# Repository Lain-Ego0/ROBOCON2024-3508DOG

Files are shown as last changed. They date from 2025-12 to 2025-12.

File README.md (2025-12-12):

# ROBOCON2024-3508DOG
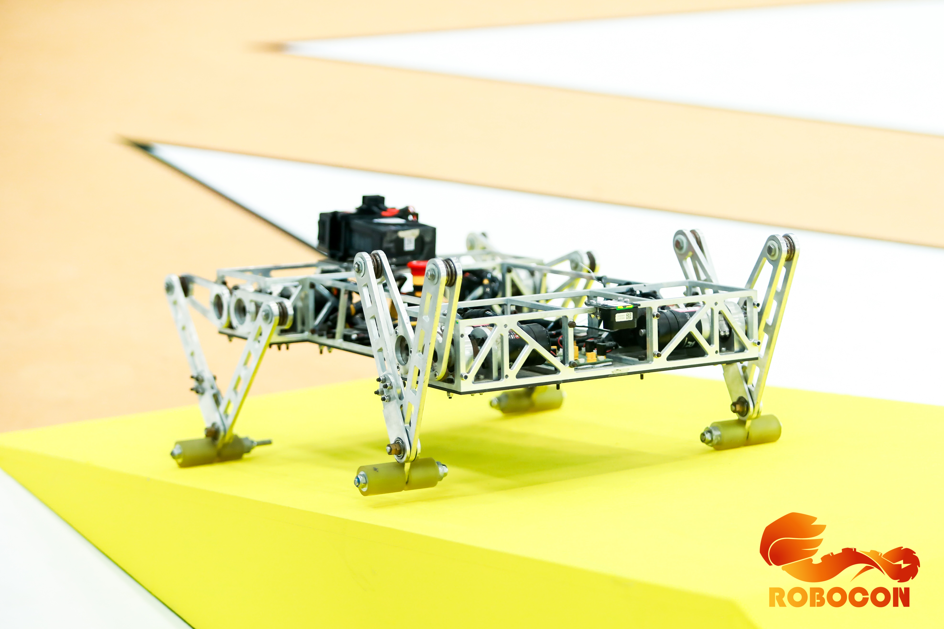
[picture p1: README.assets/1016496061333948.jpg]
Initial version developed by MTI Robotics Team, Fujian University of Technology in 2022. Iterated in 2022-2024, this DJI 3508-powered quadruped robot supports control via DJI DT7+DR16 receiver or computer keyboard (with DT7 as signal transmitter).

## 🚀 Project Overview

This project originated from the F427 basic architecture of the Robocon 2020 chassis, and officially transformed into a **quadruped robot** control program architecture after version V1.0. The core objectives are to achieve stable standing, gait control, sensor fusion of the quadruped robot, and ultimately realize autonomous or remote-controlled movement in track environments.

## 📜 Version Iteration Records

### Phase 1: Basic Chassis Architecture (V0.x)

The goal of this phase is to build a clean and stable F427 underlying platform to provide a solid foundation for subsequent complex robot projects.

| Version | Description | Main Features/Modifications |
| :--- | :--- | :--- |
| **V0.0** | Establishment of basic blank architecture | Based on the Robocon 2020 chassis, removed redundant functions, fixed warnings, and built the F427 underlying architecture. |
| **V0.1** | Code standardization | Modified most function names for ease of use; improved functions; completed comments. |
| **V0.2** | RC/Keyboard control integration | Modified the `remote` file and added keyboard control options (requires RoboMaster client). |
| **V0.3** | LiDAR integration | Added LiDAR module, connected to **Serial Port 6**. |
| **V0.4** | Preliminary integration of positioning system (WiFi) | Added positioning system functions; `Rabbit` structure; WiFi reception (Serial Port 7); zero reset transmission (Serial Port 8). |
| **V0.5** | Chassis rotation and self-made remote control | Optimized chassis rotation; added self-made 2.4G remote control (**Serial Port 2**). |
| **V0.6** | Hardware upgrade of positioning system | Removed WiFi, added RS485 absolute encoder base-axis positioning system based on C8T6 (**Serial Port 7**). |

-----

### Phase 2: Quadruped Robot Architecture (V1.x - V2.x)

This phase is the core of the project, focusing on the implementation of motion control, balance, and gait algorithms for the quadruped robot.

| Version | Description | Main Features/Modifications |
| :--- | :--- | :--- |
| **V1.0** | **Project transformation and motor allocation** | **Established the program with quadruped robot as the core project**, and allocated motors for each joint. |
| **V1.1** | **PID library and function reconstruction** | Modified the original function `M3508_ParaInit(void)` to:<br>**`M3508_ParaInit(Leg_speed_PID speed[], Leg_position_PID position[])`** to achieve **variable PID**.<br>Added remote control functions and **PID library**. |
| **V1.2** | Architecture file update | Added underlying architecture files updated to version V0.3. |
| **V1.3** | Implementation of standing function | Realized the basic **standing function** of the quadruped robot. |
| **V1.4** | Attitude balance (Gyroscope) | Added **gyroscope-based anti-fall standing function** to achieve basic attitude control. |
| **V1.5** | Attitude balance (LiDAR) | **Added LiDAR** to maintain a fixed height, aiming to solve the **backward tilting problem** during standing. |
| **V1.6** | Reconstruction of keyboard control logic | **Modified keyboard control logic** and partial control functions to adapt to quadruped robot movement. |
| **V1.7** | Gait exploration and frame number measurement | **Started frame number measurement**, and performed incremental adjustments on the basis of balance to **enable walking**. |
| **V1.8** | Introduction of time frame | Added **time frame** (start of operation) for gait timing control. |
| **V1.81** | Frame compensation algorithm | Added **frame compensation algorithm** to optimize the smoothness of gait movement. |
| **V1.9** | Keyboard logic and motion expansion | Modified keyboard logic, added **forward rotation function** (backward rotation to be added), and continued measuring frame angles. |
| **V2.0** | Logic and behavior optimization | Set sampling monitoring to 8, optimized logic and operation behavior (competition preparation phase). |
| **V2.1** | Addition of backward gait | **Added backward gait function** to realize the backward movement of the robot. |
| **V2.2** | Preset height and turning | Added **preset height** and **turning function** (PID for preset state not yet implemented). |
| **V2.3** | Track testing | Conducted track testing (**differential decision-making and jumping function**). |
| **V2.4** | Turning optimization | **Modified turning method** with improved speed. |
| **V2.5** | Track testing and improvement | Track testing improvements: **reduce height** when going down slopes; right turn assigned to Q key (not yet modified). |
| **infinity** | **Final competition testing** | **Only debugging is performed, no additional algorithms or hardware are added.** Recorded on 2023.7.2 by_kizuna |

-----

## 🛠️ Technical Implementation and Notes

### 1. M3508 Motor Parameter Initialization

In version V1.1, to achieve **variable PID**, the motor initialization function has been reconstructed and can now receive PID structure arrays as parameters, facilitating dynamic switching of control parameters in different gaits or states.

```c
// V1.1 version function declaration
void M3508_ParaInit(Leg_speed_PID speed[], Leg_position_PID position[]);
```

**【Important Note】**

When calling this function with a structure array, you must use the address operator `&` to pass the address of the first element of the array:

```c
// Example call:
M3508_ParaInit(&state_kara_speed[0], &state_kara_position[0]);
```

### 2. Structure Sharing

Structures declared and shared in `.h` files (such as those for PID parameters, remote control data, and positioning data) can be directly used anywhere in the project to ensure data consistency.

## 💡 Maintenance and Messages

This project has undergone a transformation from a basic chassis to a complex quadruped robot, reflecting the relentless efforts and pursuit of excellence of the electronic control team.

> **Message from kizuna (2023 ROBOCON Electronic Control):**
>
> **No matter how difficult it is, we refuse to give up. Chasing dreams is exactly the challenge for us** ――《LoveLive!》

> **Message from Liangchen Jason (2024 ROBOCON Electronic Control):**
>
> **Improve architecture files, add functions, refine and enhance their capabilities, and carry out version iteration.**

> **Message from Ming (Recorded on 2024.7.8):**
>
> **Keep your heart focused on the goal, and with consistent effort day after day, progress is inevitable.**

# Original Turning Data
// Left Turn
float go_left1[8]={0,26,42,-18,-99,-106,-49,-2};//
float go_left2[8]={0,39,52,93,111,30,-8,-17};//
float go_left3[8]={99,18,-42,-26,0,2,49,106};//
float go_left4[8]={-111,-93,-52,-39,0,17,8,-30};//

float go_left5[8]={111,83,52,39,0,-17,-8,30};//
float go_left6[8]={-99,-18,42,26,0,-2,-49,-106};//
float go_left7[8]={0,-39,-52,-83,-111,-30,8,17};//
float go_left8[8]={0,-26,-42,18,99,106,49,2};//
// Right Turn
float go_right1[8]={0,-2,-49,-106,-99,-18,42,26};//
float go_right2[8]={0,-17,-8,30,111,93,52,39};
float go_right3[8]={99,106,49,2,0,-26,-42,18};
float go_right4[8]={-111,-30,8,17,0,-39,-52,-93};

float go_right5[8]={111,30,-8,-17,0,39,52,83};//
float go_right6[8]={-99,-106,-49,-2,0,26,42,-18};//
float go_right7[8]={0,17,8,-30,-111,-83,-52,-39};
float go_right8[8]={0,2,49,106,99,18,-42,-26};

# New Turning Data (Based on Step State)
// Left
float Ttabu1[8]={0,-40,-80,-129,-142,-44,-16,14};
float Ttabu2[8]={0,-28,-25,11,111,100,52,26};
float Ttabu3[8]={73,77,39,5,0,-46,-31,19};
float Ttabu4[8]={-101,-8,18,37,0,-26,-55,-121};

float Ttabu5[8]={73,77,39,5,0,-46,-31,19};
float Ttabu6[8]={-101,-8,18,37,0,-26,-55,-121};
float Ttabu7[8]={0,-40,-79,-129,-142,-44,-16,14};
float Ttabu8[8]={0,-28,-25,11,111,100,52,26};

// Right
float Ttabu1[8]={0,26,42,-18,-99,-106,-49,-2};
float Ttabu2[8]={0,39,52,93,111,30,-8,-17};
float Ttabu3[8]={100,75,50,25,0,25,50,75};
float Ttabu4[8]={-100,-75,-50,-25,0,-25,-50,-75};

float Ttabu5[8]={100,75,50,25,0,25,50,75};
float Ttabu6[8]={-100,-75,-50,-25,0,-25,-50,-75};
float Ttabu7[8]={0,26,42,-18,-99,-106,-49,-2};
float Ttabu8[8]={0,39,52,93,111,30,-8,-17};
**Modification Date: 2024/6/22**
// Right
float Ttabu1[8]={0,26,42,-18,-99,-106,-49,-2};
float Ttabu2[8]={0,39,52,93,111,30,-8,-17};
float Ttabu3[8]={100,8,-16,36,0,26,54,115};
float Ttabu4[8]={-100,-90,-49,-5,0,46,31,-19};

float Ttabu5[8]={100,8,-16,36,0,26,54,115};
float Ttabu6[8]={-100,-90,-49,-5,0,46,31,-19};
float Ttabu7[8]={0,26,42,-18,-99,-106,-49,-2};
float Ttabu8[8]={0,39,52,93,111,30,-8,-17};
**Modification Date: 2024/6/30**

# ROBOCON2024-3508DOG
由福建理工大学MTI机器人队于2022年设计初版，2022、2023、2024迭代，使用大疆3508电机的机械狗。可通过大疆DT7+DR16接收机或者使用DT7作为信号发射器通过电脑键盘遥控。

## 🚀 项目简介

本项目起始于 Robocon 2020 底盘的 F427 基础架构，在 V1.0 版本后正式转型为**四足机器人**的控制程序架构。核心目标是实现四足机器人的稳定站立、步态控制、传感器融合，并最终实现赛道环境下的自主或遥控运动。

## 📜 版本迭代记录

### 阶段一：基础底盘架构 (V0.x)

此阶段的目标是建立一个干净、稳定的 F427 底层平台，为后续复杂的机器人项目提供坚实基础。

| 版本 | 描述 | 主要功能/修改 |
| :--- | :--- | :--- |
| **V0.0** | 基础空白架构建立 | 基于 Robocon 2020 底盘，去除功能，修缮警告，建立 F427 底层架构。 |
| **V0.1** | 代码规范化 | 修改大部分函数名，使其使用方便；完善函数；完善注释。 |
| **V0.2** | RC/键盘控制集成 | 修改 `remote` 文件，加入键盘控制选项（需使用 RoboMaster 客户端）。 |
| **V0.3** | 激光雷达集成 | 加入激光雷达模块，放于**串口 6**。 |
| **V0.4** | 定位系统初步集成 (WiFi) | 加入定位系统功能；`Rabbit` 结构体；WiFi 接收（串口 7）；归零发送（串口 8）。 |
| **V0.5** | 底盘旋转与自制遥控 | 优化底盘旋转；加入自制 2.4G 遥控（**串口 2**）。 |
| **V0.6** | 定位系统硬件升级 | 删除 WiFi，加入基于 C8T6 的 RS485 绝对值编码器基轴定位系统（**串口 7**）。 |

-----

### 阶段二：四足机器人架构 (V1.x - V2.x)

此阶段是项目的核心，聚焦于四足机器人的运动控制、平衡和步态算法实现。

| 版本 | 描述 | 主要功能/修改 |
| :--- | :--- | :--- |
| **V1.0** | **项目转型与电机分配** | **建立以四足机器人为项目的程序**，并分配好各关节电机。 |
| **V1.1** | **PID 库与函数重构** | 修改原函数 `M3508_ParaInit(void)` 为：<br>**`M3508_ParaInit(Leg_speed_PID speed[], Leg_position_PID position[])`**，实现**可变 PID**。<br>加入遥控控制函数和**PID 库**。 |
| **V1.2** | 架构文件更新 | 加入更新至 V0.3 版本的底层架构文件。 |
| **V1.3** | 站立功能实现 | 实现四足机器人基本的**站立功能**。 |
| **V1.4** | 姿态平衡\*\*（陀螺仪）\*\* | 加入**陀螺仪站立不倒**功能，实现基础姿态控制。 |
| **V1.5** | 姿态平衡\*\*（激光雷达）\*\* | **增加激光雷达**维持一定高度，欲解决站立时的**后倾问题**。 |
| **V1.6** | 键盘控制逻辑重构 | **修改键盘控制逻辑**，以及部分控制函数，以适应四足机器人运动。 |
| **V1.7** | 步态探索与帧数测量 | **开始进行帧数测量**，在平衡的基础上进行加法，**欲使其可以走路**。 |
| **V1.8** | 时间帧引入 | 加入**时间帧**（开始运行）作为步态时序控制。 |
| **V1.81** | 补帧算法 | 加入**补帧算法**，优化步态运动的平滑性。 |
| **V1.9** | 键盘逻辑与运动扩展 | 修改键盘逻辑，加入可以**前转功能**（后转待加入），继续测量帧数角。 |
| **V2.0** | 逻辑与行为优化 | 监测采样 8，优化逻辑以及运行行为（备赛阶段）。 |
| **V2.1** | 后步态加入 | **后步态**功能加入，实现机器人的后退运动。 |
| **V2.2** | 预设与转弯 | 加入**预设高度**，以及**转弯功能**（预设状态 PID 尚未进行）。 |
| **V2.3** | 赛道测试 | 进行赛道测试（**差决策以及跳跃功能**）。 |
| **V2.4** | 转弯优化 | **修改转弯方式**，速度有所提升。 |
| **V2.5** | 赛道测试与改进 | 赛道测试改进：下斜坡时应**降低高度**；右转为 Q 键尚未更改。 |
| **infinity** | **比赛最终测试** | **仅进行调试，不再加入算法以及其他硬件。** 记录于 2023.7.2 by\_kizuna |

-----

## 🛠️ 技术实现与注意事项

### 1\. M3508 电机参数初始化

在 V1.1 版本，为了实现**可变 PID**，电机初始化函数已被重构，现可接收 PID 结构体数组作为参数，方便在不同步态或状态下动态切换控制参数。

```c
// V1.1 版本函数声明
void M3508_ParaInit(Leg_speed_PID speed[], Leg_position_PID position[]);
```

**【重要提示】**

在使用结构体数组调用此函数时，必须使用指向符 `&` 传递数组首元素的地址：

```c
// 示例调用：
M3508_ParaInit(&state_kara_speed[0], &state_kara_position[0]);
```

### 2\. 结构体共享

位于 `.h` 文件中声明并共享的结构体（如用于 PID 参数、遥控数据、定位数据的结构体）可以在项目的任何地方直接使用，确保数据的一致性。

## 💡 维护与寄语

本项目经历了从基础底盘到复杂四足机器人的转型，体现了电控团队不懈的努力和追求卓越的精神。

> **kizuna (2023 ROBOCON 电控) 赠语:**
>
> **无论多么艰难也不愿放弃，追梦正是对我们的挑战** ――《lovelive》

> **良辰Jason (2024 ROBOCON 电控) 赠语:**
>
> **完善架构文件，加入功能，并对其修缮提升其功能，进行版本迭代。**

> **詺 (2024.7.8 记录) 寄语:**
>
> **心有所向，日复一日，必有精进。**
# 原转弯数据
//左转
float go_left1[8]={0,26,42,-18,-99,-106,-49,-2};//
float go_left2[8]={0,39,52,93,111,30,-8,-17};//
float go_left3[8]={99,18,-42,-26,0,2,49,106};//
float go_left4[8]={-111,-93,-52,-39,0,17,8,-30};//

float go_left5[8]={111,83,52,39,0,-17,-8,30};//
float go_left6[8]={-99,-18,42,26,0,-2,-49,-106};//
float go_left7[8]={0,-39,-52,-83,-111,-30,8,17};//
float go_left8[8]={0,-26,-42,18,99,106,49,2};//
//右转
float go_right1[8]={0,-2,-49,-106,-99,-18,42,26};//
float go_right2[8]={0,-17,-8,30,111,93,52,39};
float go_right3[8]={99,106,49,2,0,-26,-42,18};
float go_right4[8]={-111,-30,8,17,0,-39,-52,-93};

float go_right5[8]={111,30,-8,-17,0,39,52,83};//
float go_right6[8]={-99,-106,-49,-2,0,26,42,-18};//
float go_right7[8]={0,17,8,-30,-111,-83,-52,-39};
float go_right8[8]={0,2,49,106,99,18,-42,-26};
转弯的新数据（基于踏步状态）
//Left
float Ttabu1[8]={0,-40,-80,-129,-142,-44,-16,14};
float Ttabu2[8]={0,-28,-25,11,111,100,52,26};
float Ttabu3[8]={73,77,39,5,0,-46,-31,19};
float Ttabu4[8]={-101,-8,18,37,0,-26,-55,-121};

float Ttabu5[8]={73,77,39,5,0,-46,-31,19};
float Ttabu6[8]={-101,-8,18,37,0,-26,-55,-121};
float Ttabu7[8]={0,-40,-79,-129,-142,-44,-16,14};
float Ttabu8[8]={0,-28,-25,11,111,100,52,26};

//Right
float Ttabu1[8]={0,26,42,-18,-99,-106,-49,-2};
float Ttabu2[8]={0,39,52,93,111,30,-8,-17};
float Ttabu3[8]={100,75,50,25,0,25,50,75};
float Ttabu4[8]={-100,-75,-50,-25,0,-25,-50,-75};

float Ttabu5[8]={100,75,50,25,0,25,50,75};
float Ttabu6[8]={-100,-75,-50,-25,0,-25,-50,-75};
float Ttabu7[8]={0,26,42,-18,-99,-106,-49,-2};
float Ttabu8[8]={0,39,52,93,111,30,-8,-17};
**修改时间2024/6/22**
//Right
float Ttabu1[8]={0,26,42,-18,-99,-106,-49,-2};
float Ttabu2[8]={0,39,52,93,111,30,-8,-17};
float Ttabu3[8]={100,8,-16,36,0,26,54,115};
float Ttabu4[8]={-100,-90,-49,-5,0,46,31,-19};

float Ttabu5[8]={100,8,-16,36,0,26,54,115};
float Ttabu6[8]={-100,-90,-49,-5,0,46,31,-19};
float Ttabu7[8]={0,26,42,-18,-99,-106,-49,-2};
float Ttabu8[8]={0,39,52,93,111,30,-8,-17};
**修改时间2024/6/30**

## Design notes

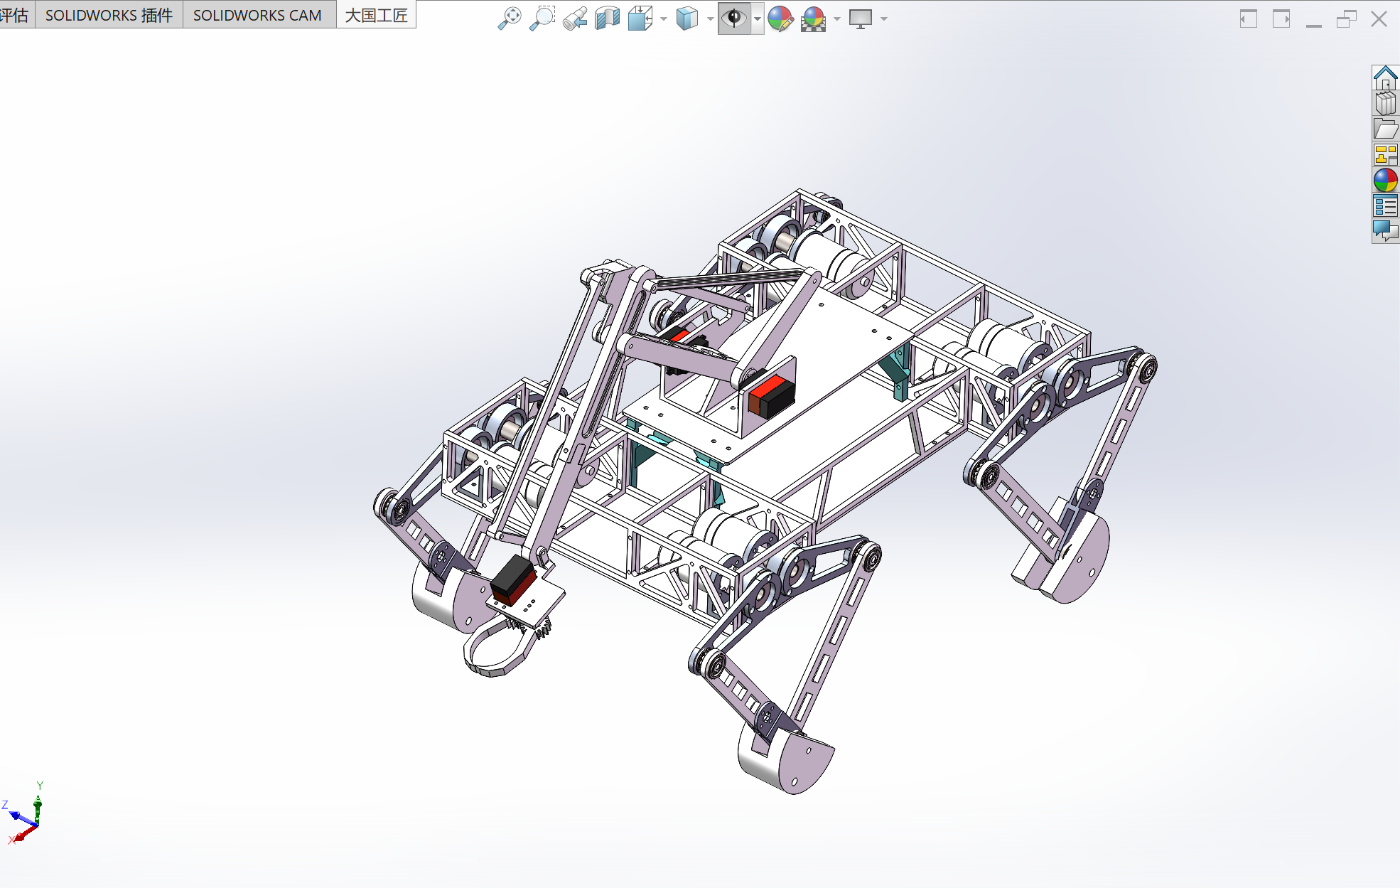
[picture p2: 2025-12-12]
5.Images/Snipaste_2025-12-12_08-36-43.png

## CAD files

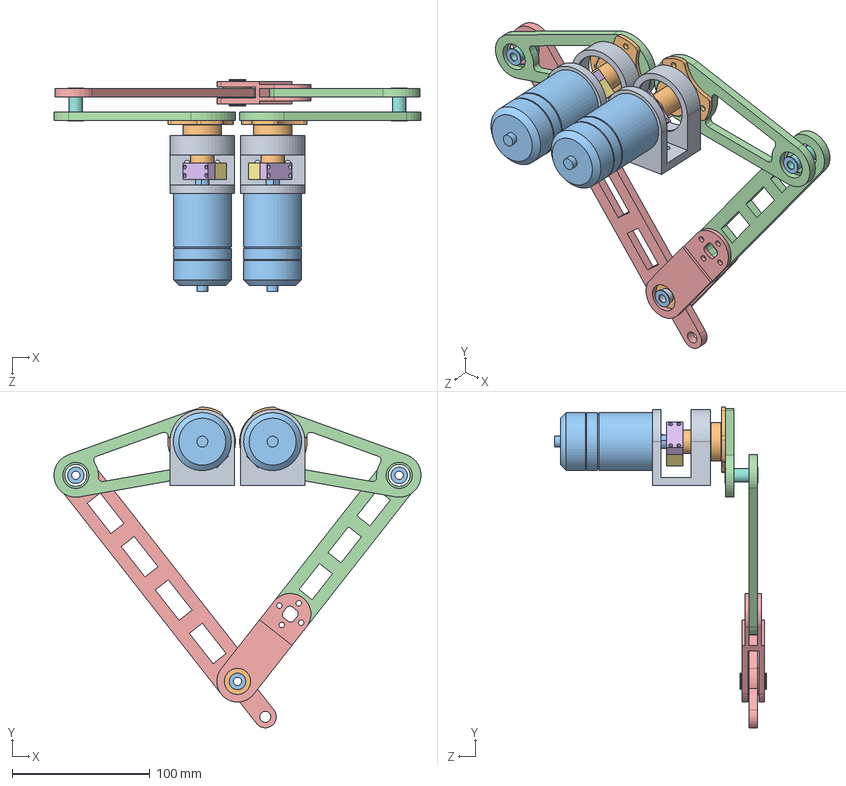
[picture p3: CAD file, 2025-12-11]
1.Hardware/腿左前右后.SLDASM
266.2 x 232.6 x 153.6 mm
3508电机座 x 2
轴 x 2
3508电机 x 2
大腿 x 2
腿部铰接
轴固定（梯形） x 2
轴固定（半圆形） x 2
尼龙套 x 2
尼龙套2
尼龙垫片 x 2
金属垫片 x 6
小腿
小腿＋脚固定

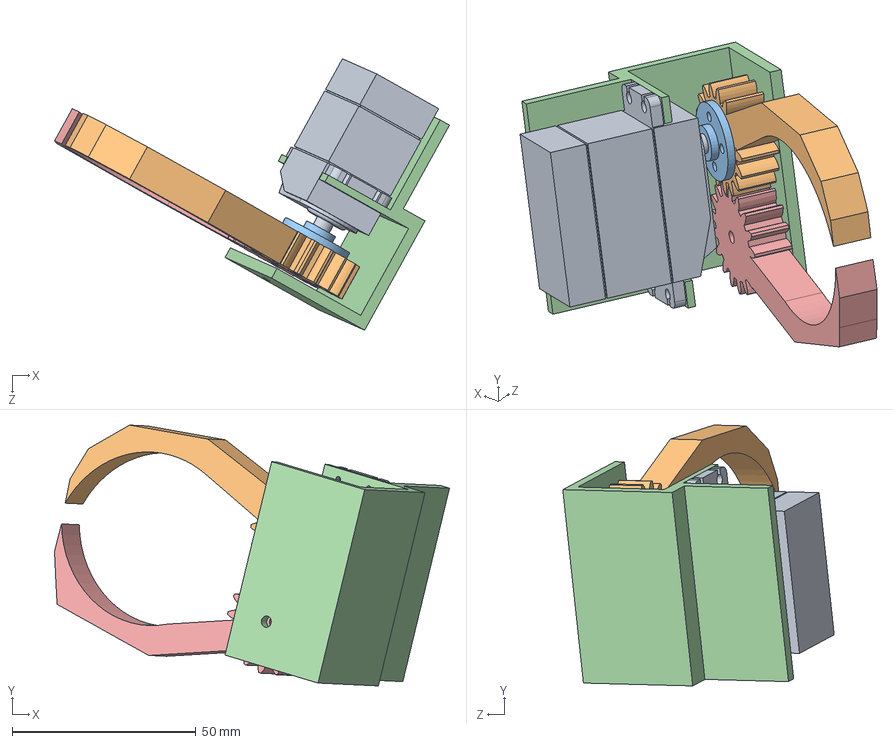
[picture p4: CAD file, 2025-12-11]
1.Hardware/爪子装配.SLDASM
107.5 x 71.0 x 73.9 mm
DT-8230舵轮
齿轮7
DT-8220的法兰
爪座
齿轮8

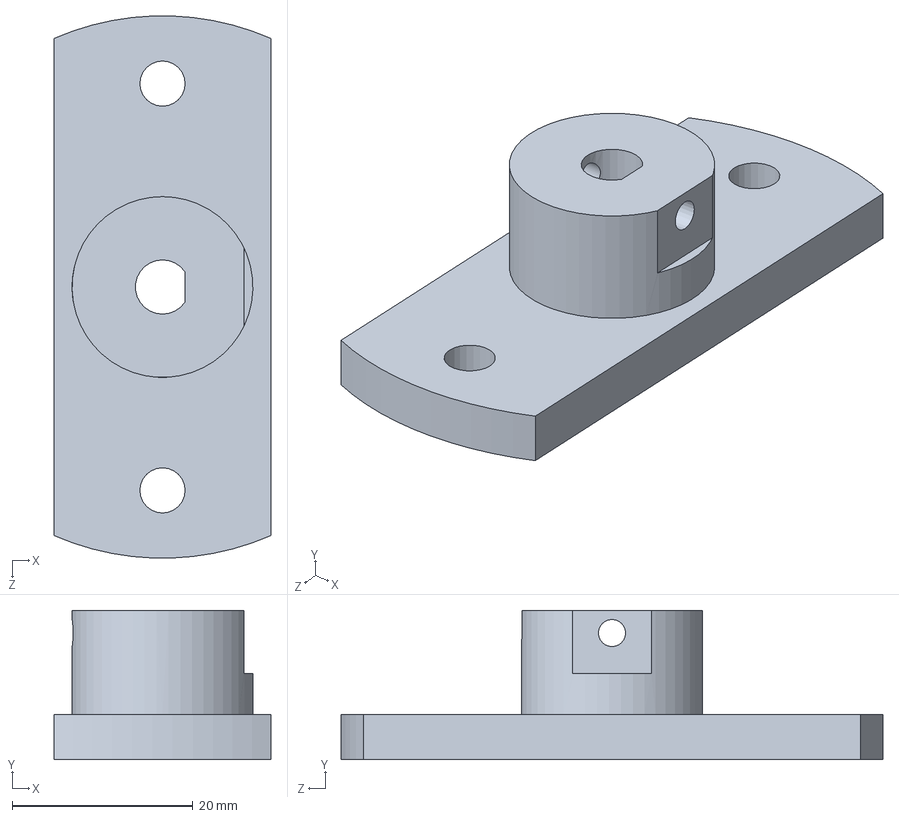
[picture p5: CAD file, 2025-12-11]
1.Hardware/2006法兰盘.SLDPRT
24.0 x 16.5 x 60.0 mm

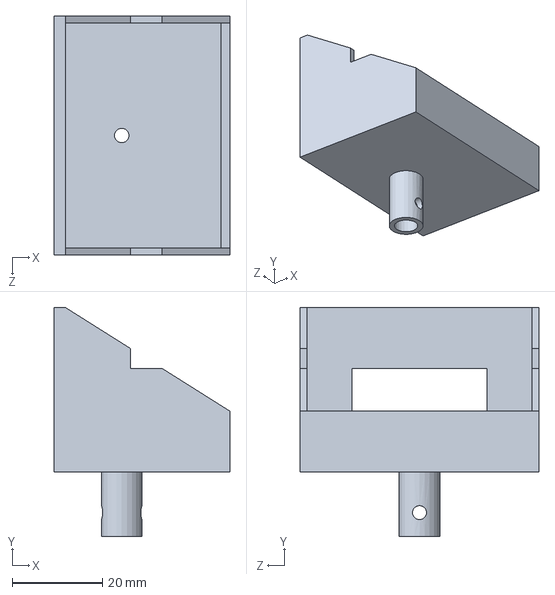
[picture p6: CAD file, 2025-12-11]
1.Hardware/废/最后的云台.SLDPRT
39.0 x 50.8 x 53.0 mm

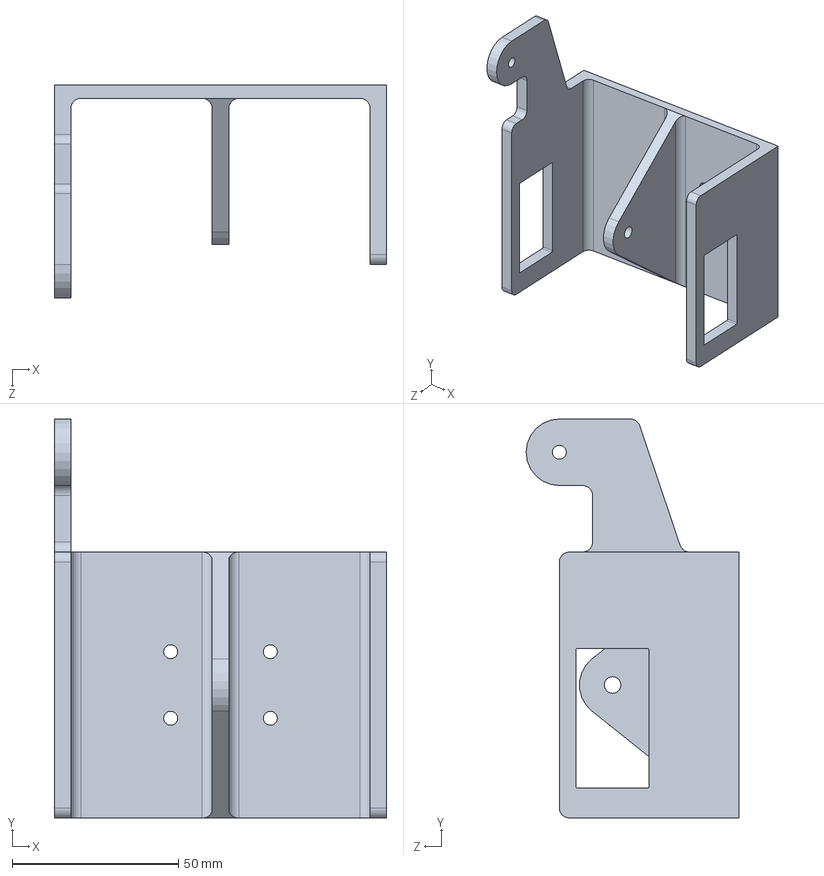
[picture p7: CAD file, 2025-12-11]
1.Hardware/机械臂/臂底座.SLDPRT
100.0 x 120.0 x 64.0 mm

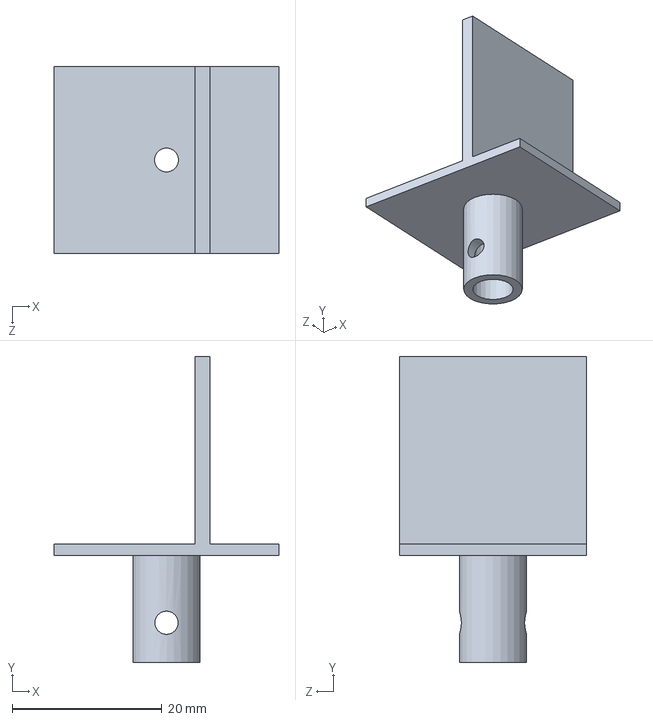
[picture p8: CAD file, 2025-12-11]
1.Hardware/废/纵向云台.SLDPRT
30.0 x 40.8 x 25.0 mm

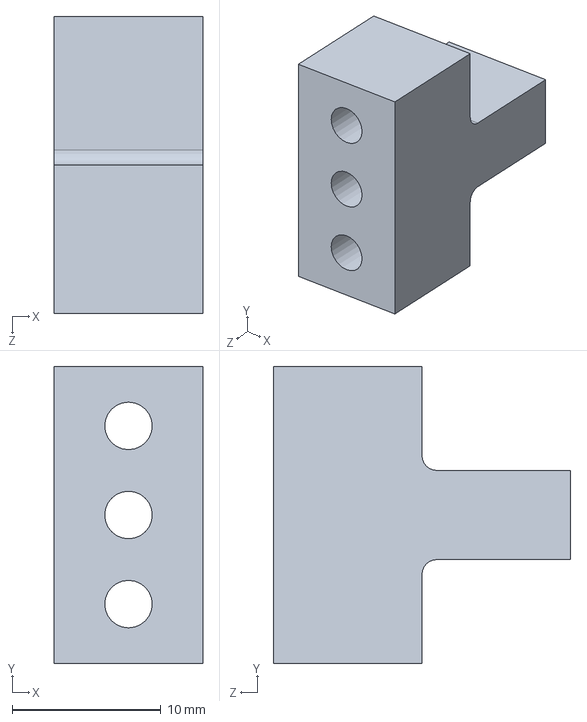
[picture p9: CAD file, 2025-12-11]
1.Hardware/机械臂/垫块.SLDPRT
10.0 x 20.0 x 20.0 mm

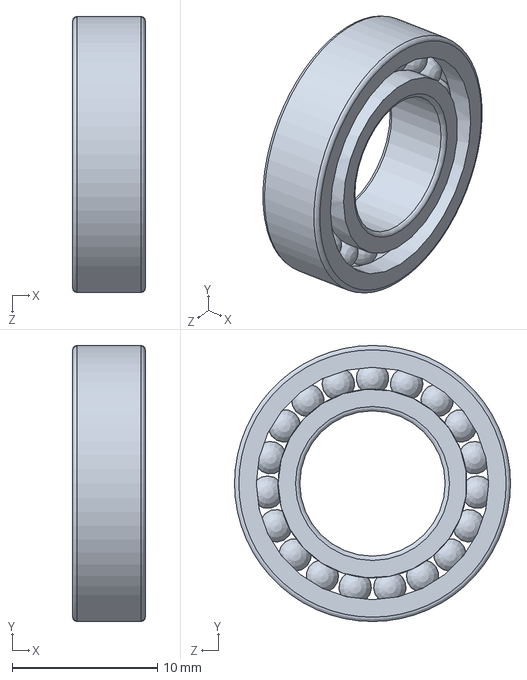
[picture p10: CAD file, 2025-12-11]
1.Hardware/深沟球轴承Rolling bearings 61800 GB 276-94.SLDPRT
5.00 x 19.0 x 19.0 mm

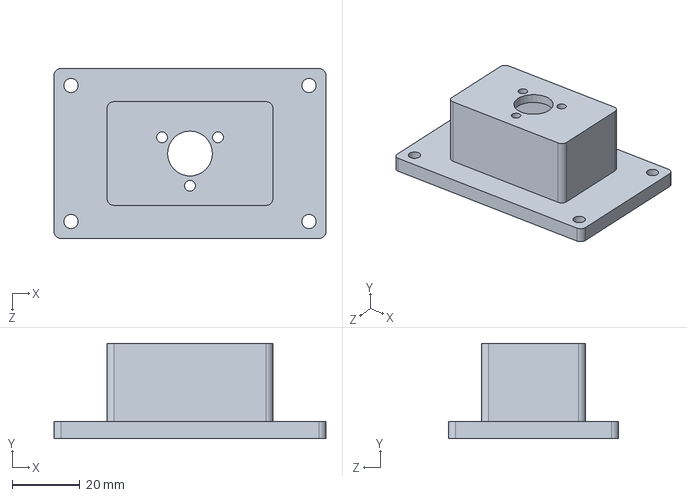
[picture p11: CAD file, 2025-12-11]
1.Hardware/废/横向云台.SLDPRT
80.0 x 28.0 x 50.0 mm

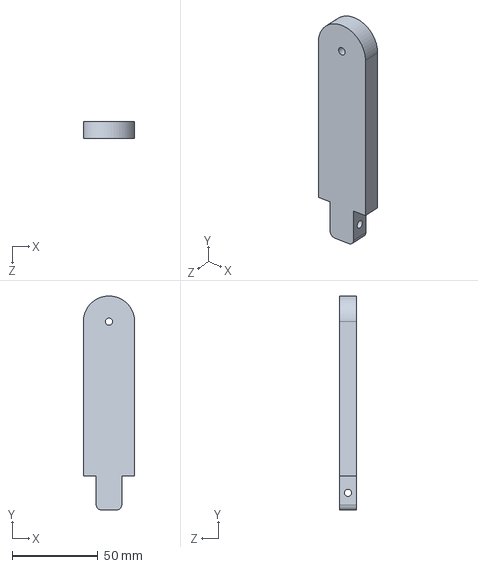
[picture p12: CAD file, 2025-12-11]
1.Hardware/机械臂/连杆3（下）.SLDPRT
30.0 x 125.0 x 10.0 mm

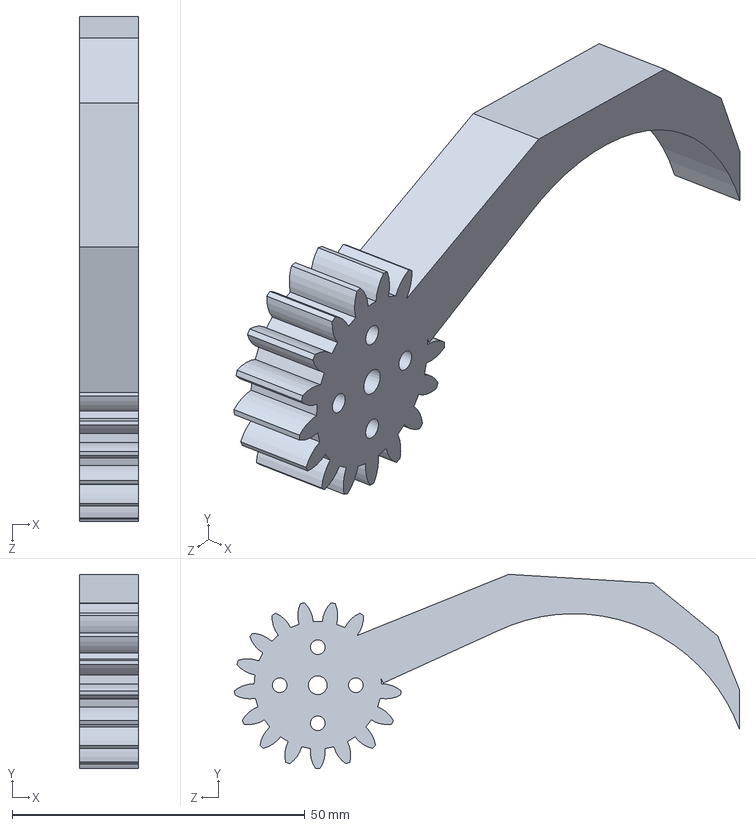
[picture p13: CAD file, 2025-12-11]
1.Hardware/齿轮7.SLDPRT
10.0 x 33.2 x 86.2 mm

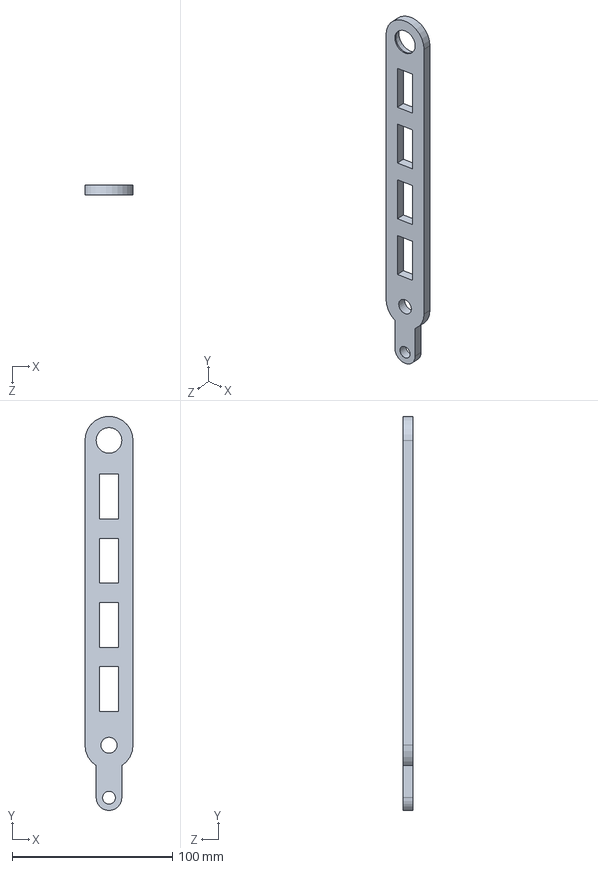
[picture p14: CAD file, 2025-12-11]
1.Hardware/小腿＋脚固定.SLDPRT
30.0 x 245.6 x 6.00 mm

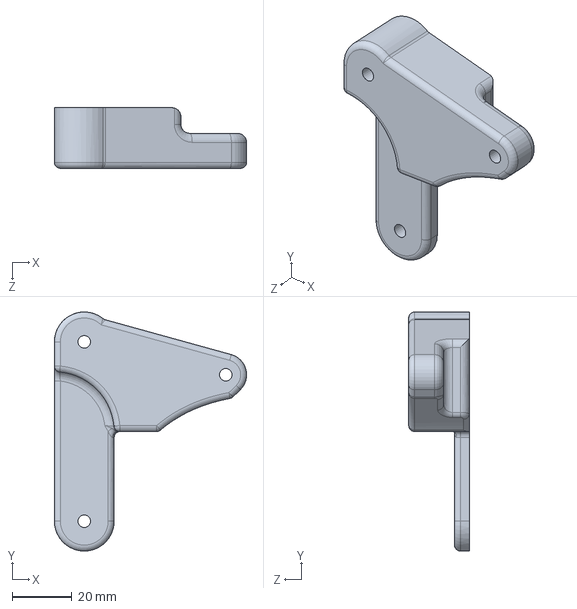
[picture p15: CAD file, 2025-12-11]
1.Hardware/机械臂/连接杆.SLDPRT
64.3 x 80.0 x 20.3 mm

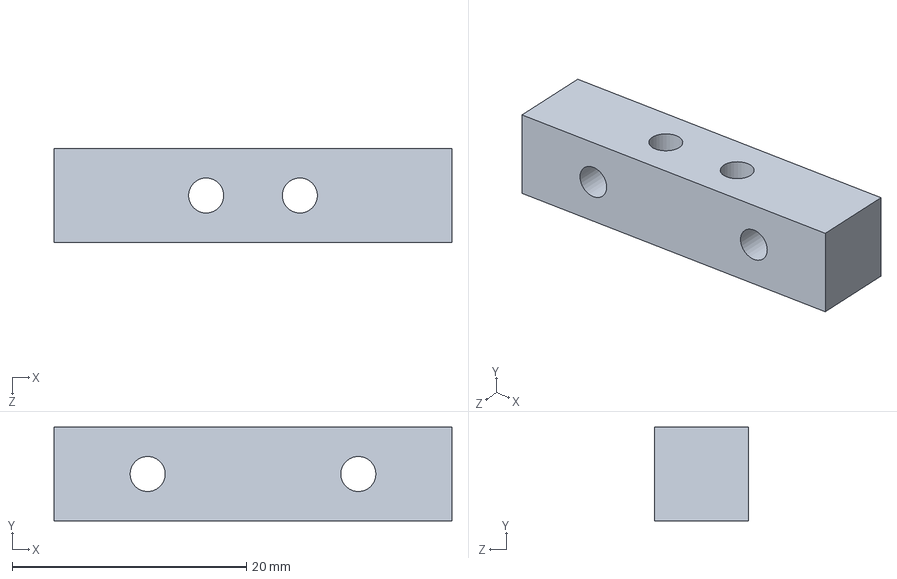
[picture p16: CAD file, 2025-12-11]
1.Hardware/六面四方螺母.SLDPRT
34.0 x 8.00 x 8.00 mm

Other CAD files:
1.Hardware/总装图.SLDASM
1.Hardware/机械臂/支撑杆.SLDPRT
1.Hardware/机械臂/连杆.SLDPRT
1.Hardware/轴.SLDPRT
1.Hardware/1.7垫片.SLDPRT
1.Hardware/3508电机.SLDPRT
1.Hardware/3508电机座.SLDPRT
1.Hardware/DP-BZJ餐桌盘轴承内圈.SLDPRT
1.Hardware/DP-BZJ餐桌盘轴承外圈.SLDPRT
1.Hardware/DT-8220的法兰.SLDPRT
1.Hardware/DT-8230舵轮.SLDPRT
1.Hardware/M3X16-H8X34六面四方螺母.SLDPRT
1.Hardware/hex bolts with slot on head grade ab gb.SLDPRT
1.Hardware/云台下底板.SLDPRT
1.Hardware/十字星.SLDPRT
1.Hardware/大腿.SLDPRT
1.Hardware/小腿.SLDPRT
1.Hardware/尼龙垫片.SLDPRT
1.Hardware/尼龙套.SLDPRT
1.Hardware/尼龙套2.SLDPRT
1.Hardware/打印垫块.SLDPRT
1.Hardware/推力球轴承Rolling bearings 51200 GB 301-1995.SLDPRT
1.Hardware/摄像头.SLDPRT
1.Hardware/支座.SLDPRT
1.Hardware/支撑板.SLDPRT
1.Hardware/机械臂/爪座.SLDPRT
1.Hardware/机械臂/连杆2.SLDPRT
1.Hardware/机械臂/连杆3（上）.SLDPRT
1.Hardware/框架管.SLDPRT
1.Hardware/狗支架.SLDPRT
1.Hardware/碳板.SLDPRT
1.Hardware/腿部铰接.SLDPRT
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

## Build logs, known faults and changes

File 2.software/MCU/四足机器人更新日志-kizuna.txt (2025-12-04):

0.0以Robocon_2020底盘为主去除功能，修缮警告，建立空白架构F427底层架构
0.1修改大部分函数名，使其使用方便，完善函数，完善注释
0.2修改remote文件，加入键盘控制选项（需使用robomaster客户端）修改于英雄
0.3加入激光雷达模块，放于串口6
1.0建立以四足机器人为项目的程序，并分配好电机
1.1修改原函数M3508_ParaInit（void）改为M3508_ParaInit(Leg_speed_PID speed[],Leg_position_PID position[])，加入可变PID，加入遥控控制函数，加入PID库，
1.2加入更新至0.3版本的架构文件
1.3站立功能
1.4陀螺仪站立不倒
1.5增加激光雷达维持一定高度，欲解决后倾问题
1.6改入键盘控制逻辑，修改控制逻辑以及部分控制函数
1.7开始进行帧数测量，在平衡的基础上进行加法，欲使其可以走路
1.8加入时间帧（开始运行）
1.81加入补帧算法
1.9修改键盘逻辑加入可以前转功能(后转待加入),继续测量帧数角
2.0.监测采样8，优化逻辑以及运行行为（备赛）
2.1.后步态加入
2.2.加入预设高度，以及转弯(未进行预设状态pid)
infinity-进入最终比赛测试仅进行调试，不在加入算法以及其他硬件_记录于2023.7.2 by_kizuna
2.3.赛道测试（差决策以及跳跃）
////////////////////////////////////////////////////////////////////////////////////////////////////////////////////////////////
2.4修改转弯方式，速度有所提升 
2.5赛道测试（下斜坡时应降低高度，右转为Q键尚未更改）
记录于2024.7.8 by_詺 心有所向，日复一日，必有精进。
//如果使用结构体数组，M3508_ParaInit(&state_kara_speed[0],&state_kara_position[0]);需要在前面加指向符& 位于h文件共享的结构体可以在任何地方使用

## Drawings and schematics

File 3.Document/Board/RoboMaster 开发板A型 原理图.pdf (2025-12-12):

# PowerTree

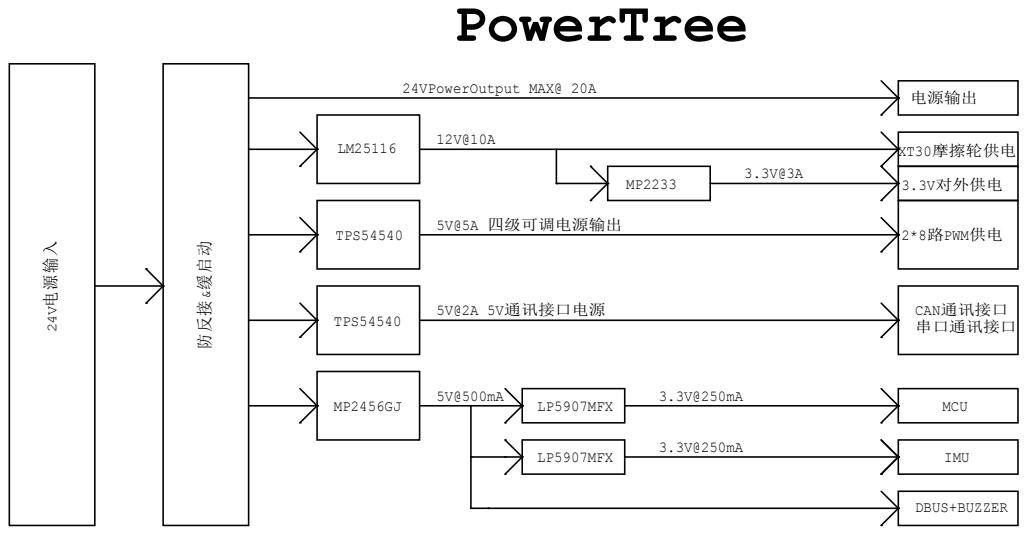
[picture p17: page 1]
A ²⁴V电源输入; 防反接&缓启动; TPS54540; 5V@5A 四级可调电源输出; 5V@2A 5V通讯接口电源; LP5907MFX; MCU; IMU; CAN通讯接口 串口通讯接口; 2*8路PWM供电; 3.3V对外供电; XT30摩擦轮供电; DBUS+BUZZER; 3.3V@250mA LP5907MFX; Title; Size; Document Number; Rev; Date:; Sheet; <Doc>; <RevCode>; <Title>; Tuesday, April 10, 2018

电源输出 ²⁴VPowerOutput MAX@ 20A

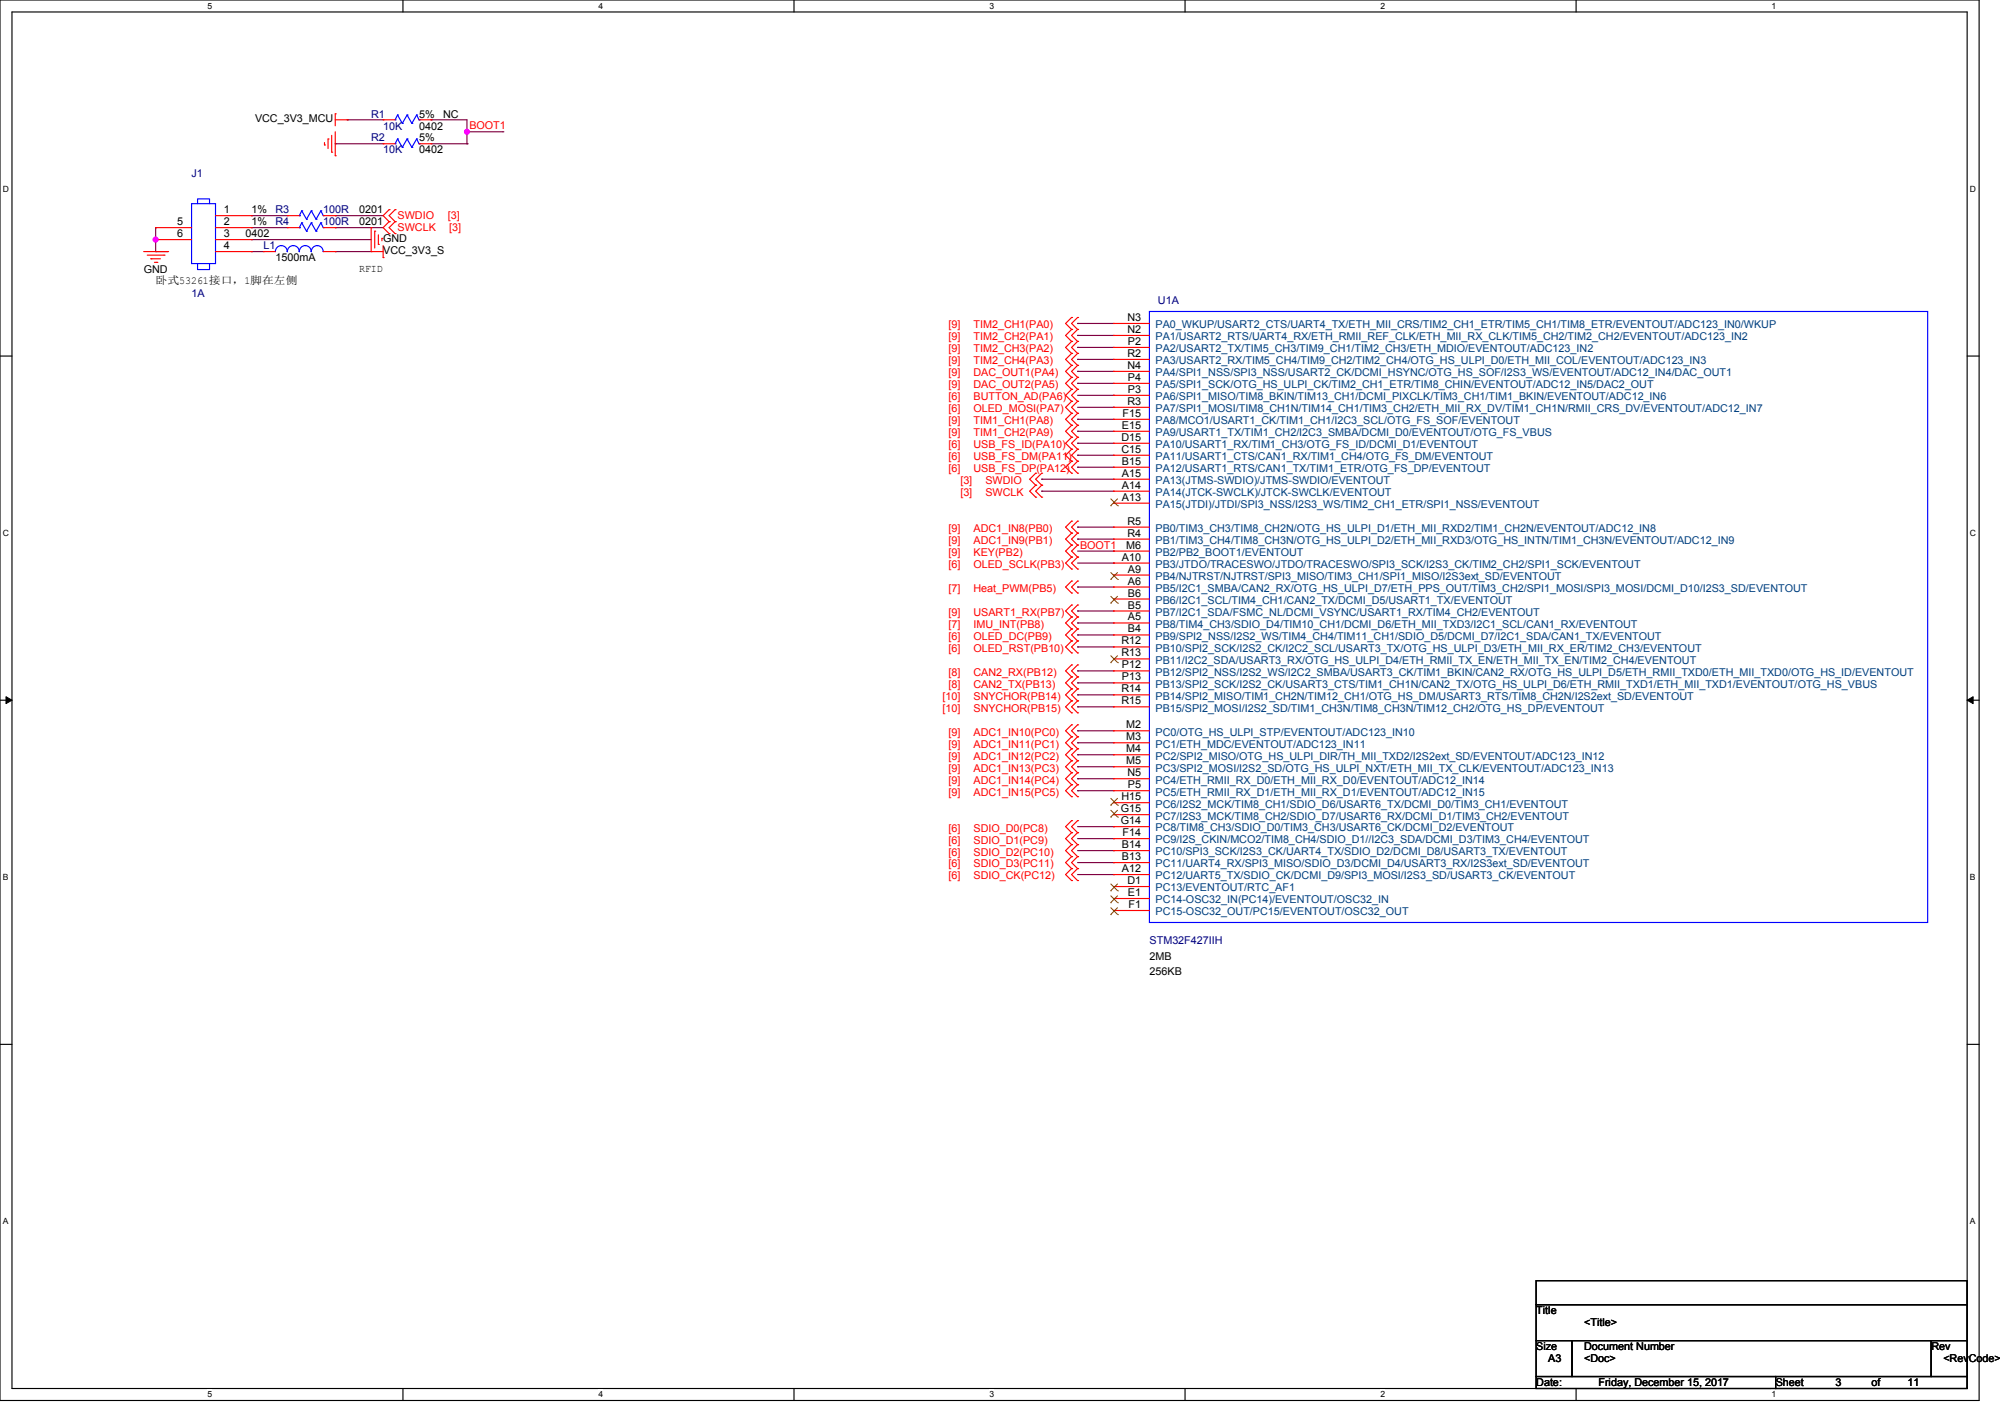
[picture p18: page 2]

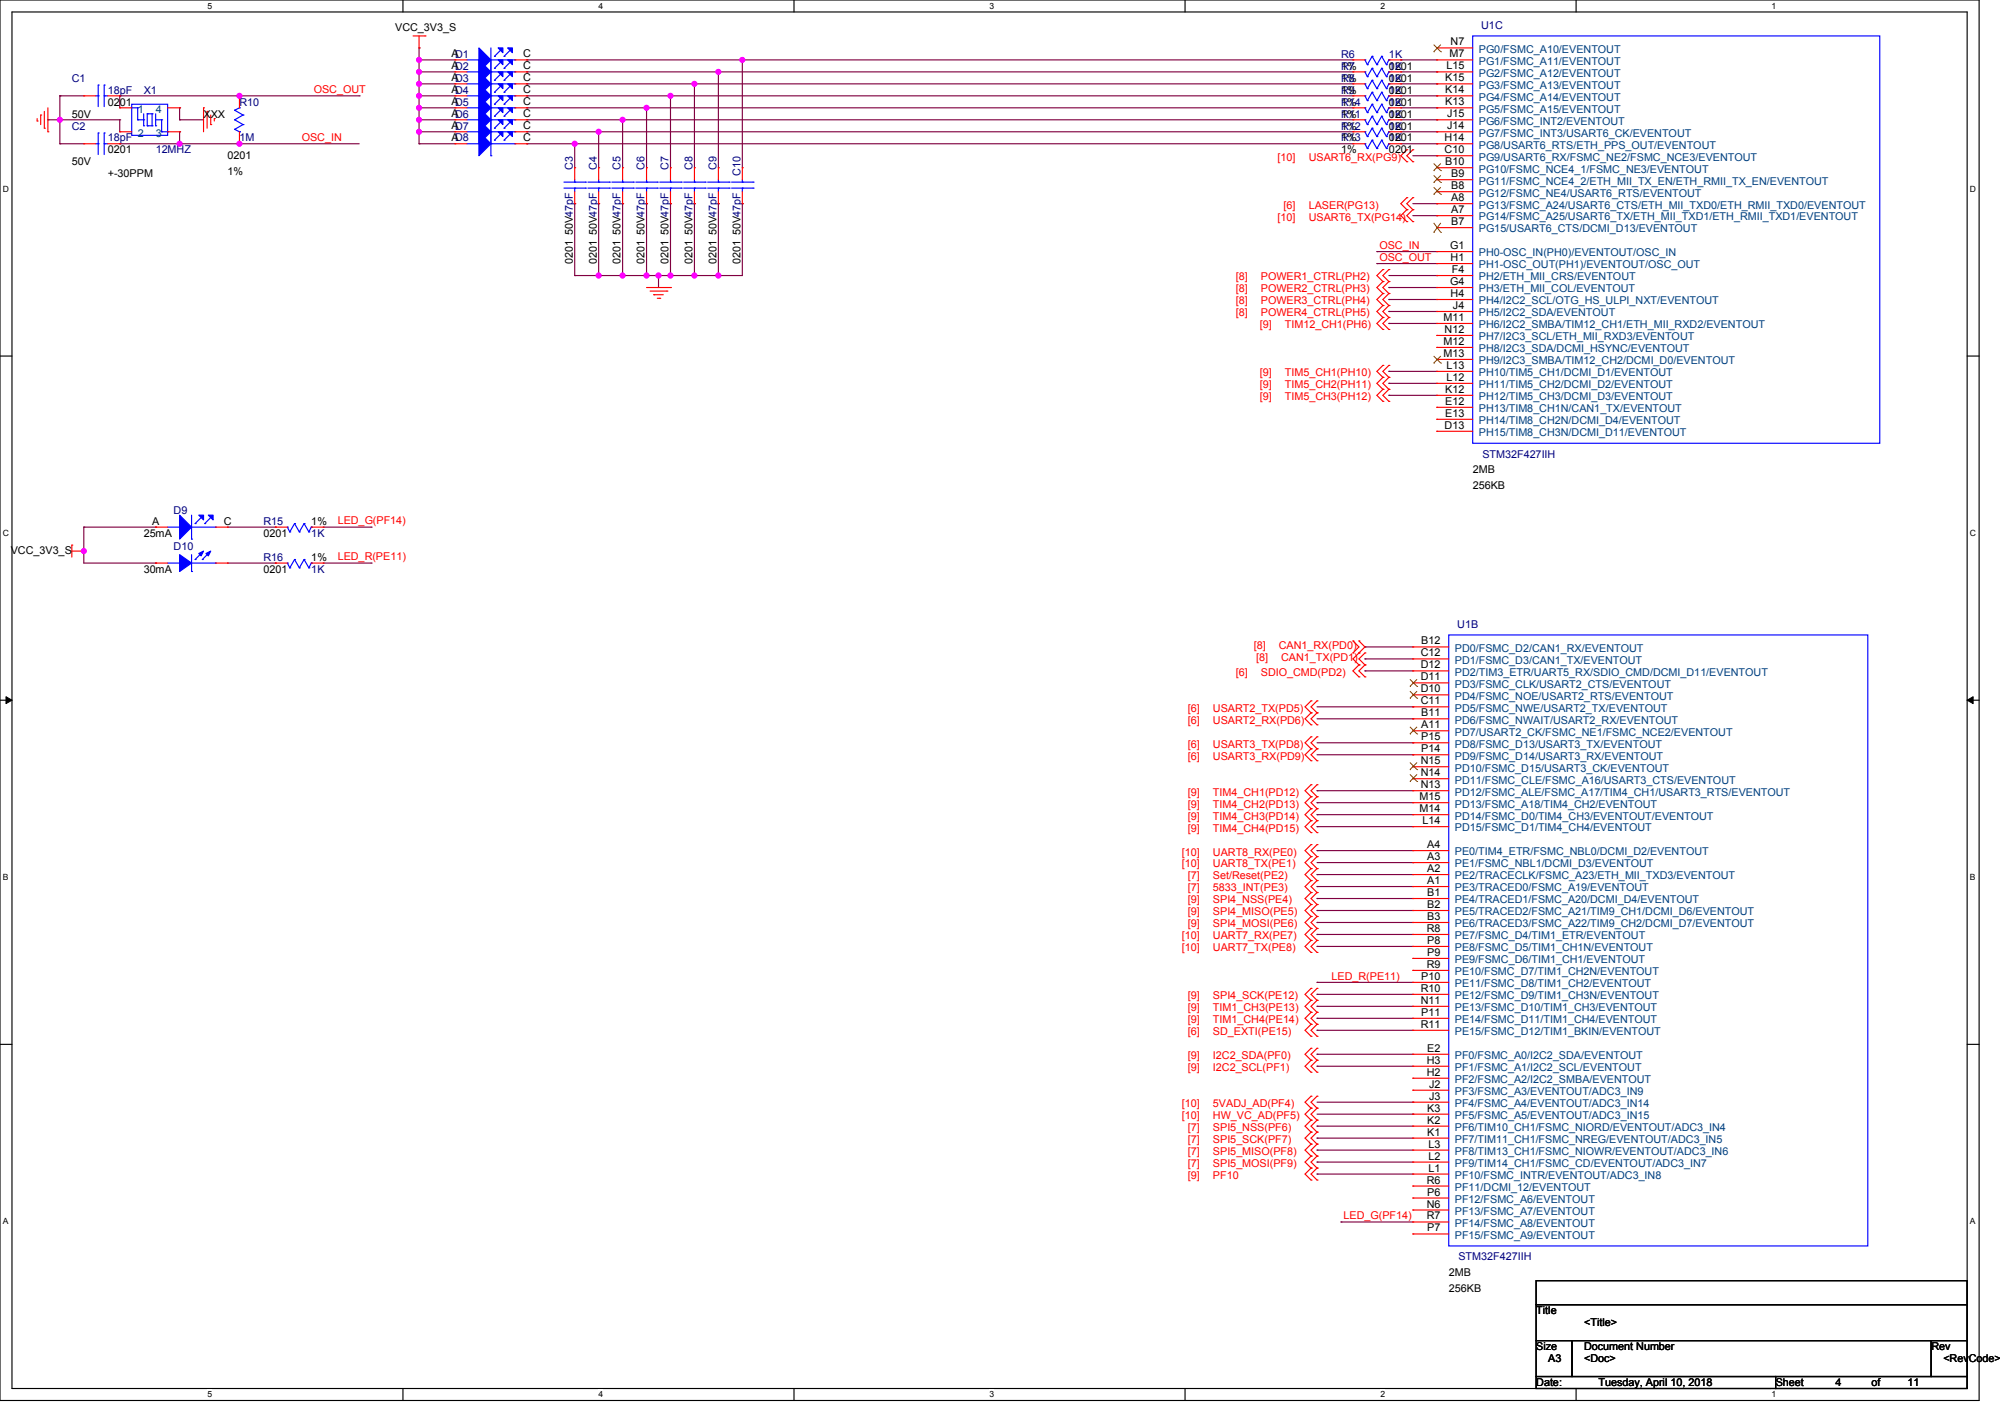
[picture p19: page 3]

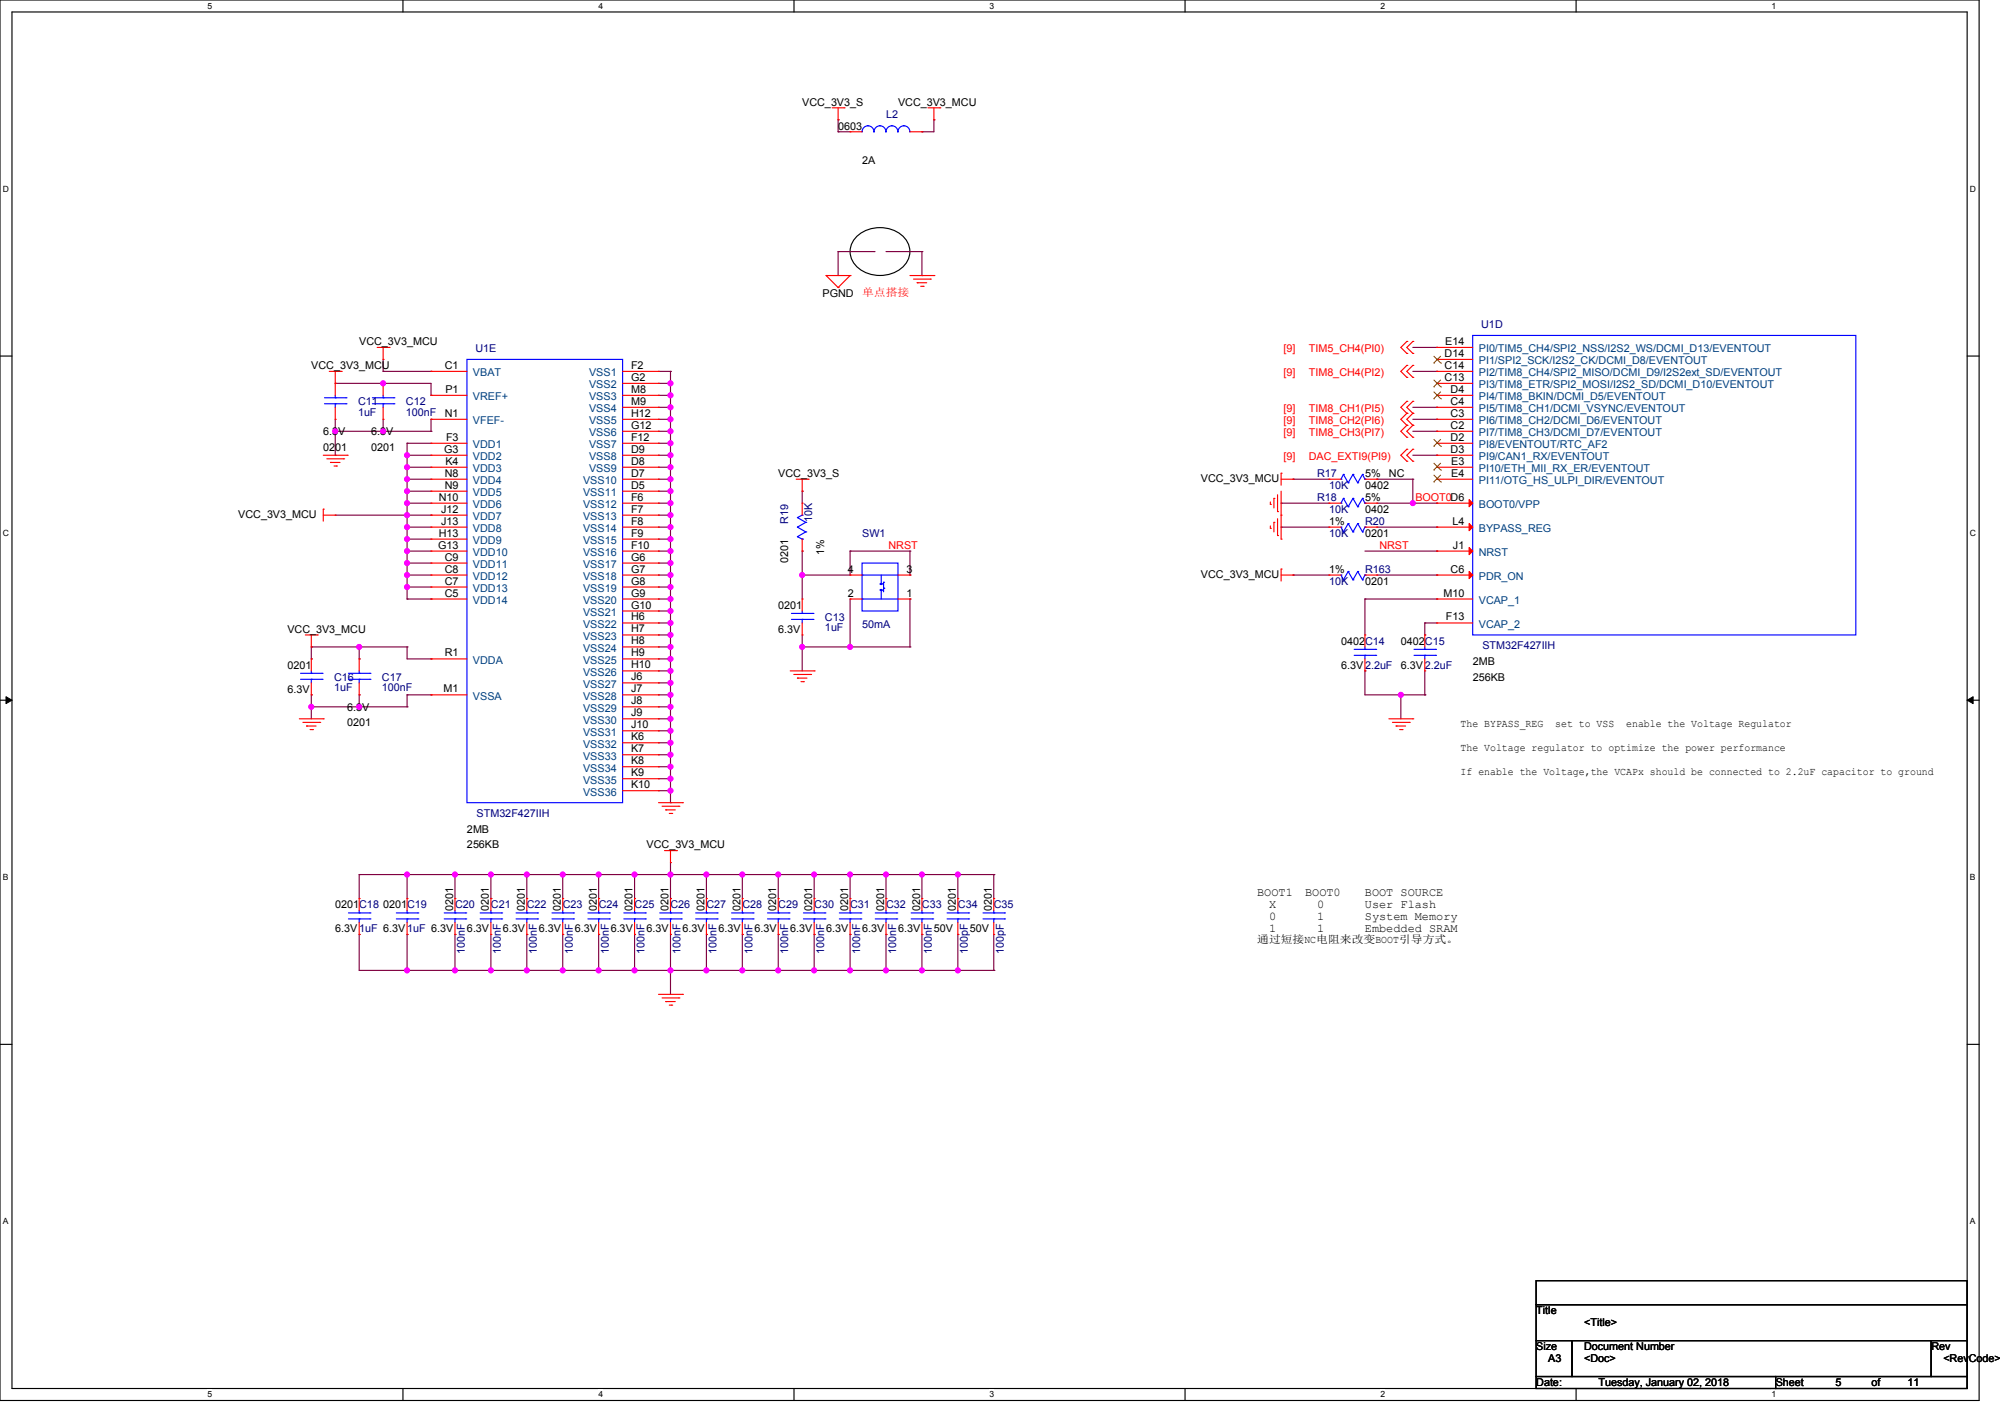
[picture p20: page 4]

The Voltage regulator to optimize the power performance

If enable the Voltage,the VCAPx should be connected to 2.2uF capacitor to ground

# 电源和CAN输入

On Board SDK 通讯接口 | Micro_SD

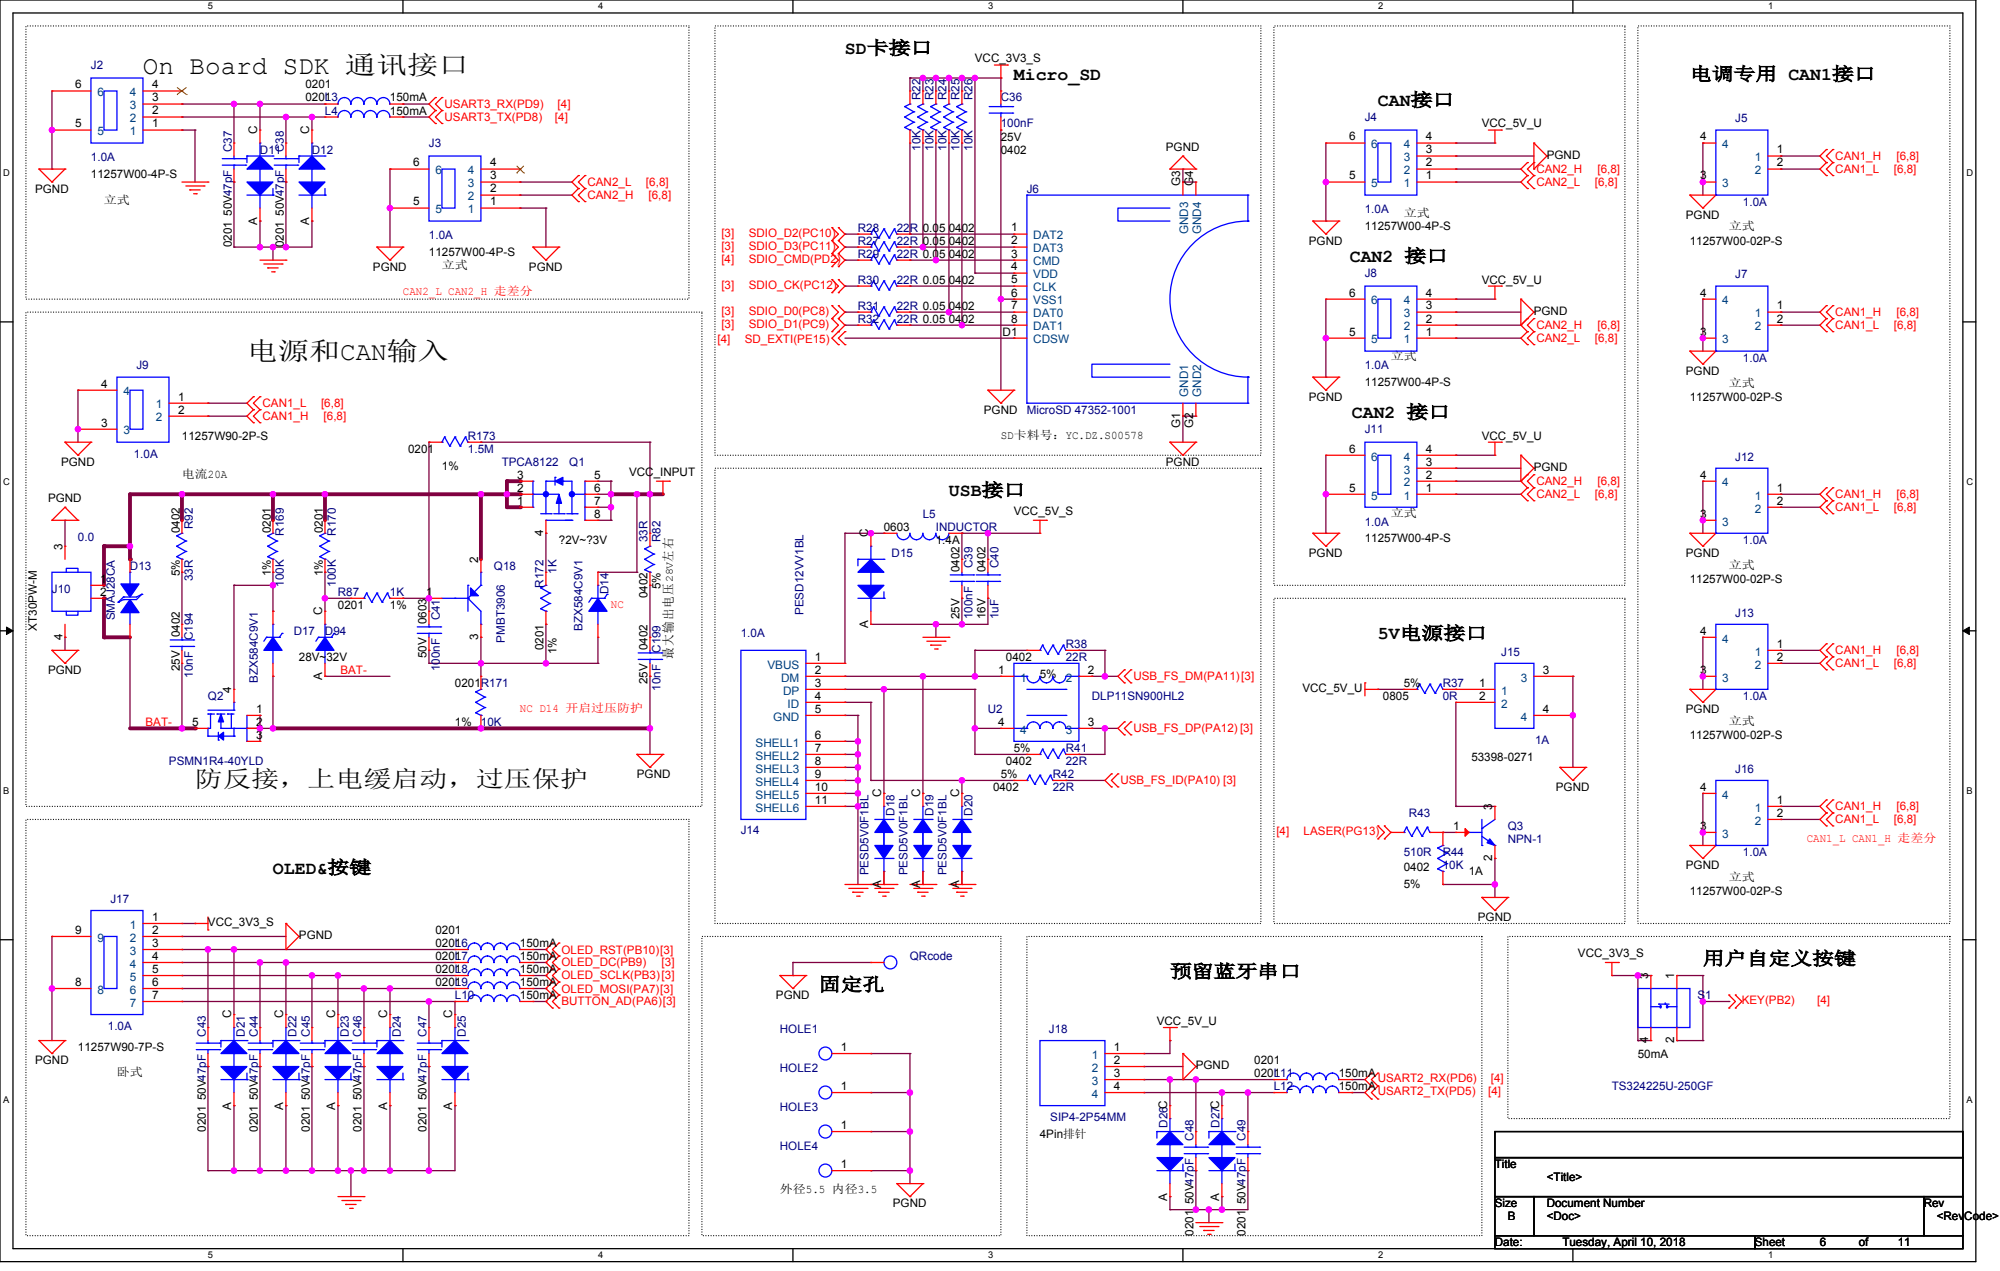
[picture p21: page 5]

## Buzzer

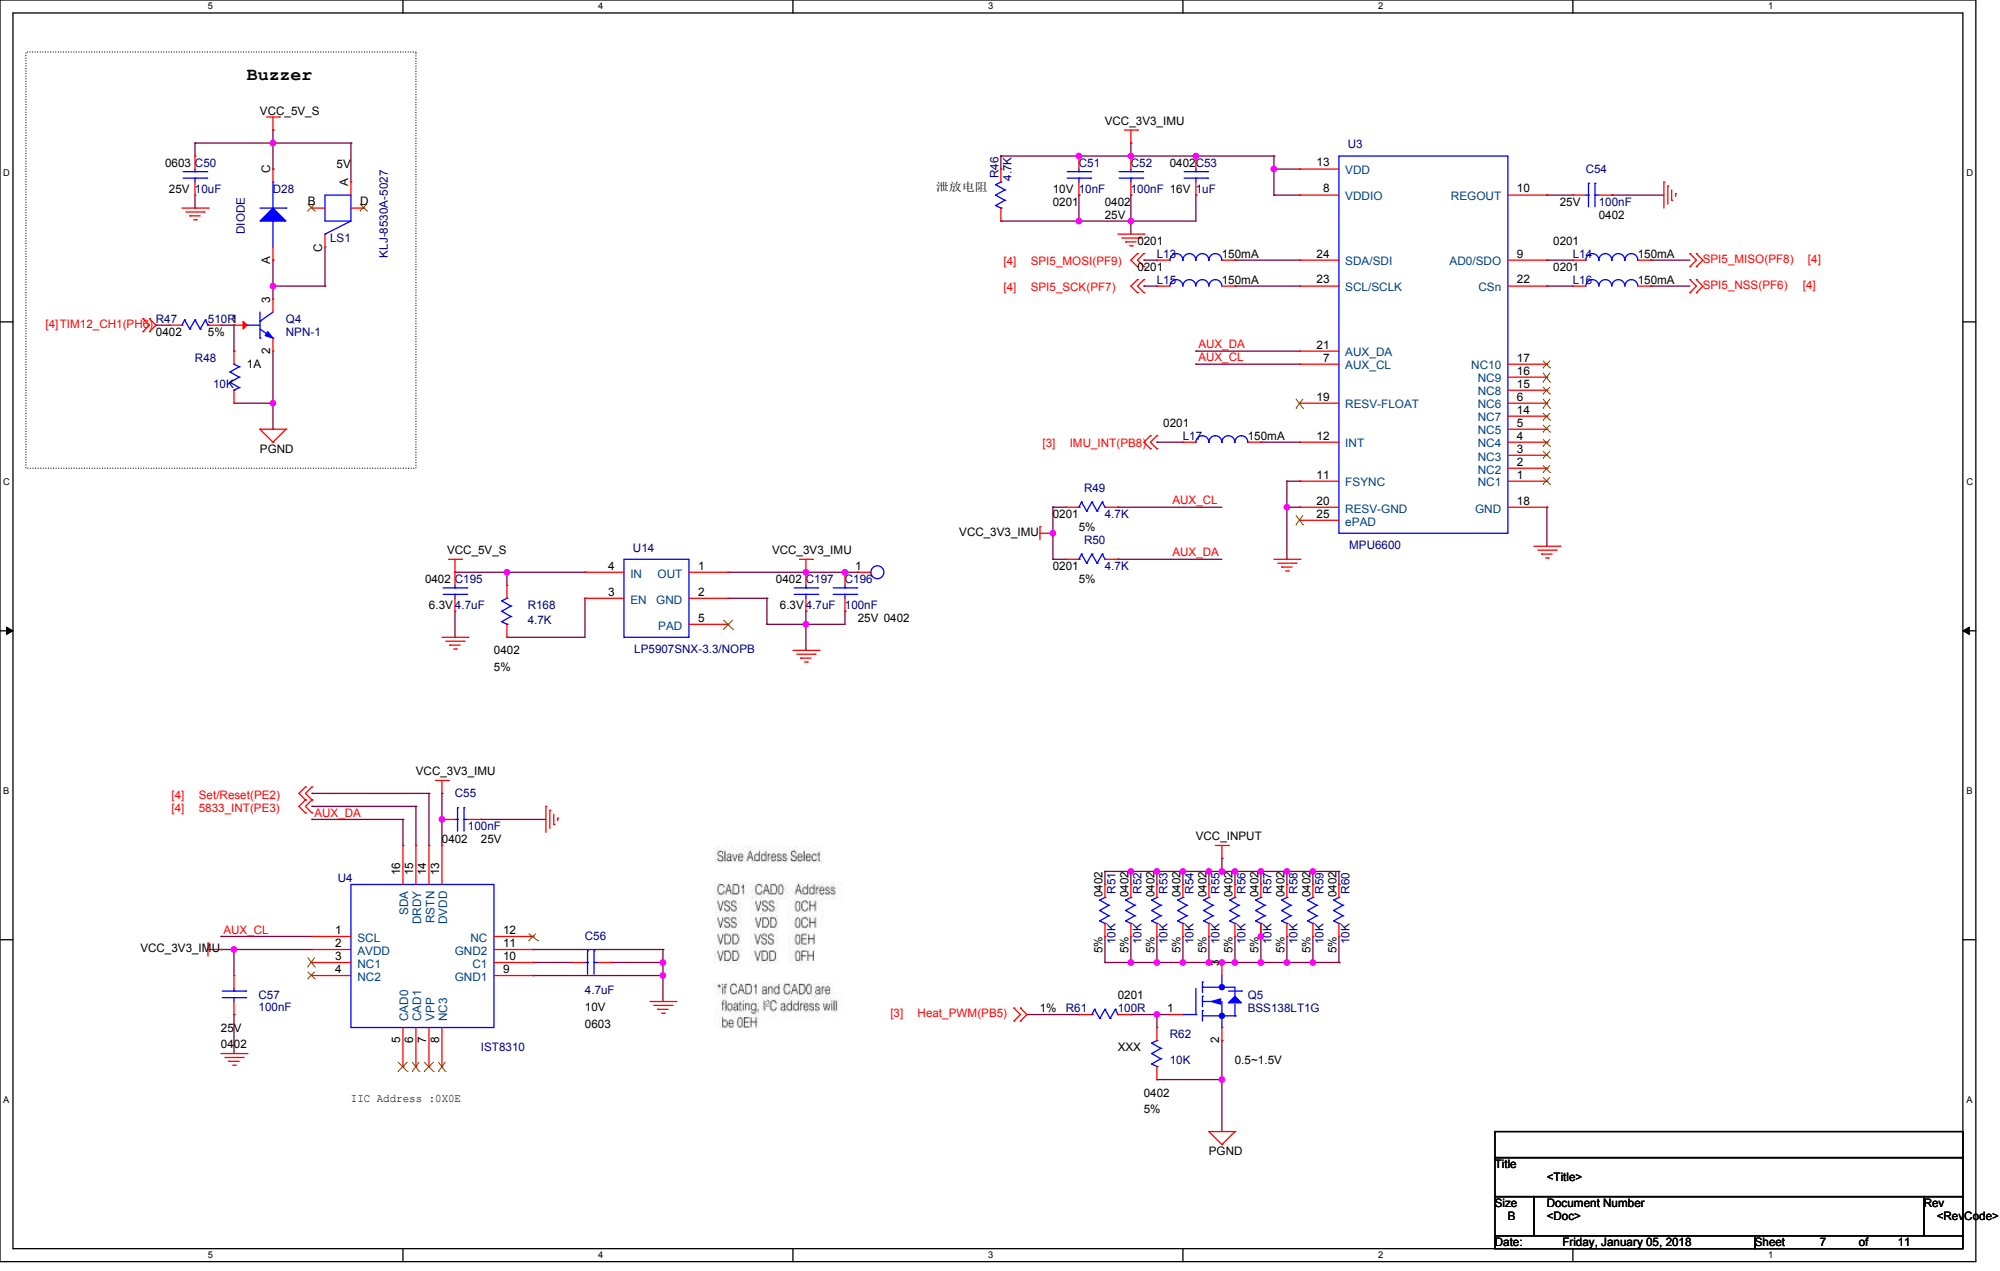
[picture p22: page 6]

DVDD 13 RSTN 14 DRDY 15 SDA 16

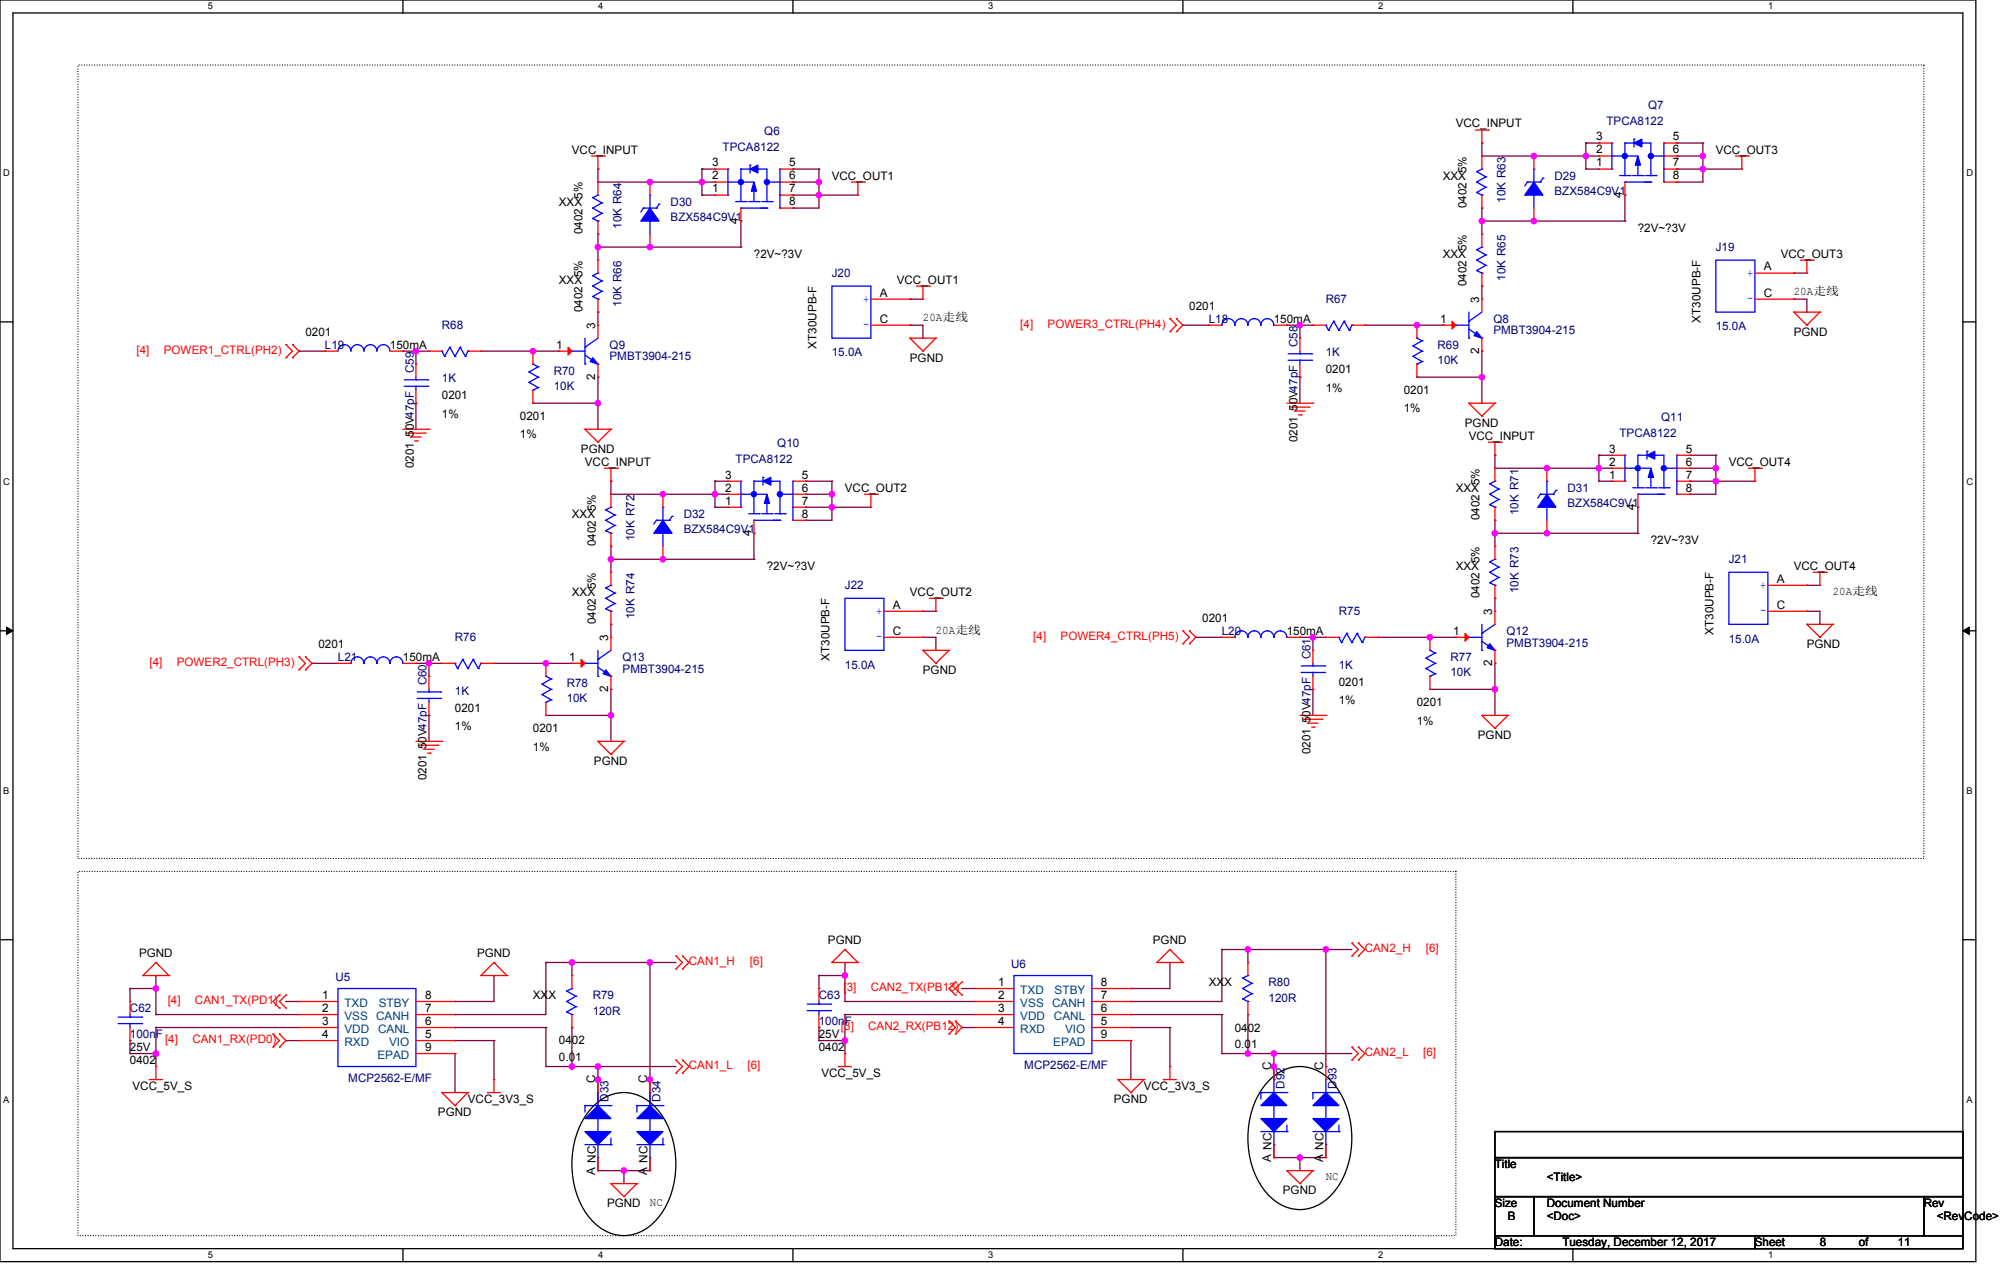
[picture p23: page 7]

# 8路PWM输出

# DBUS

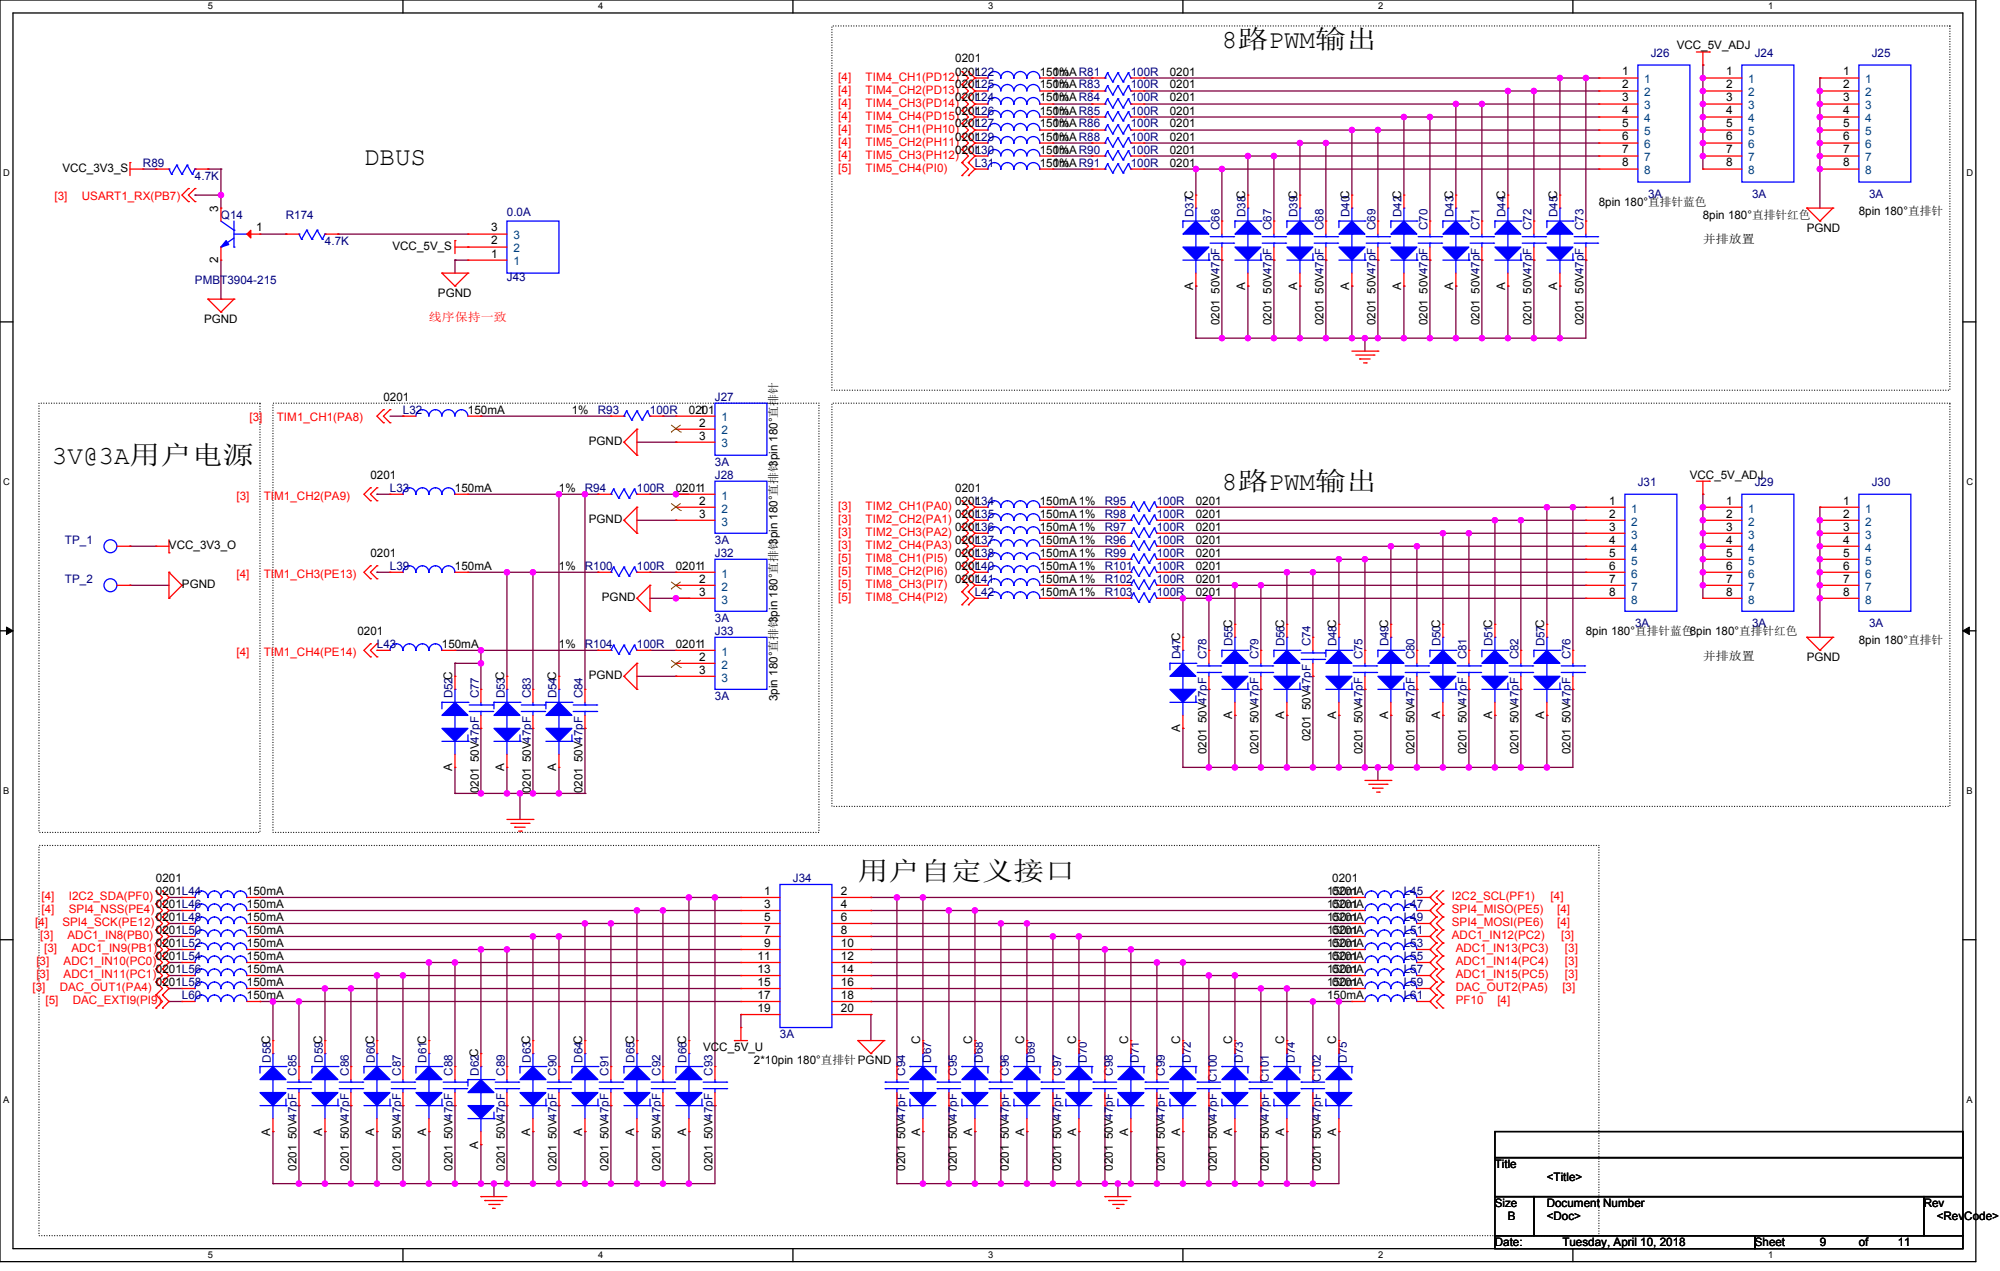
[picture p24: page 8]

可调5V电源电压采集 | 硬件版本控制

# 5V 同步信号

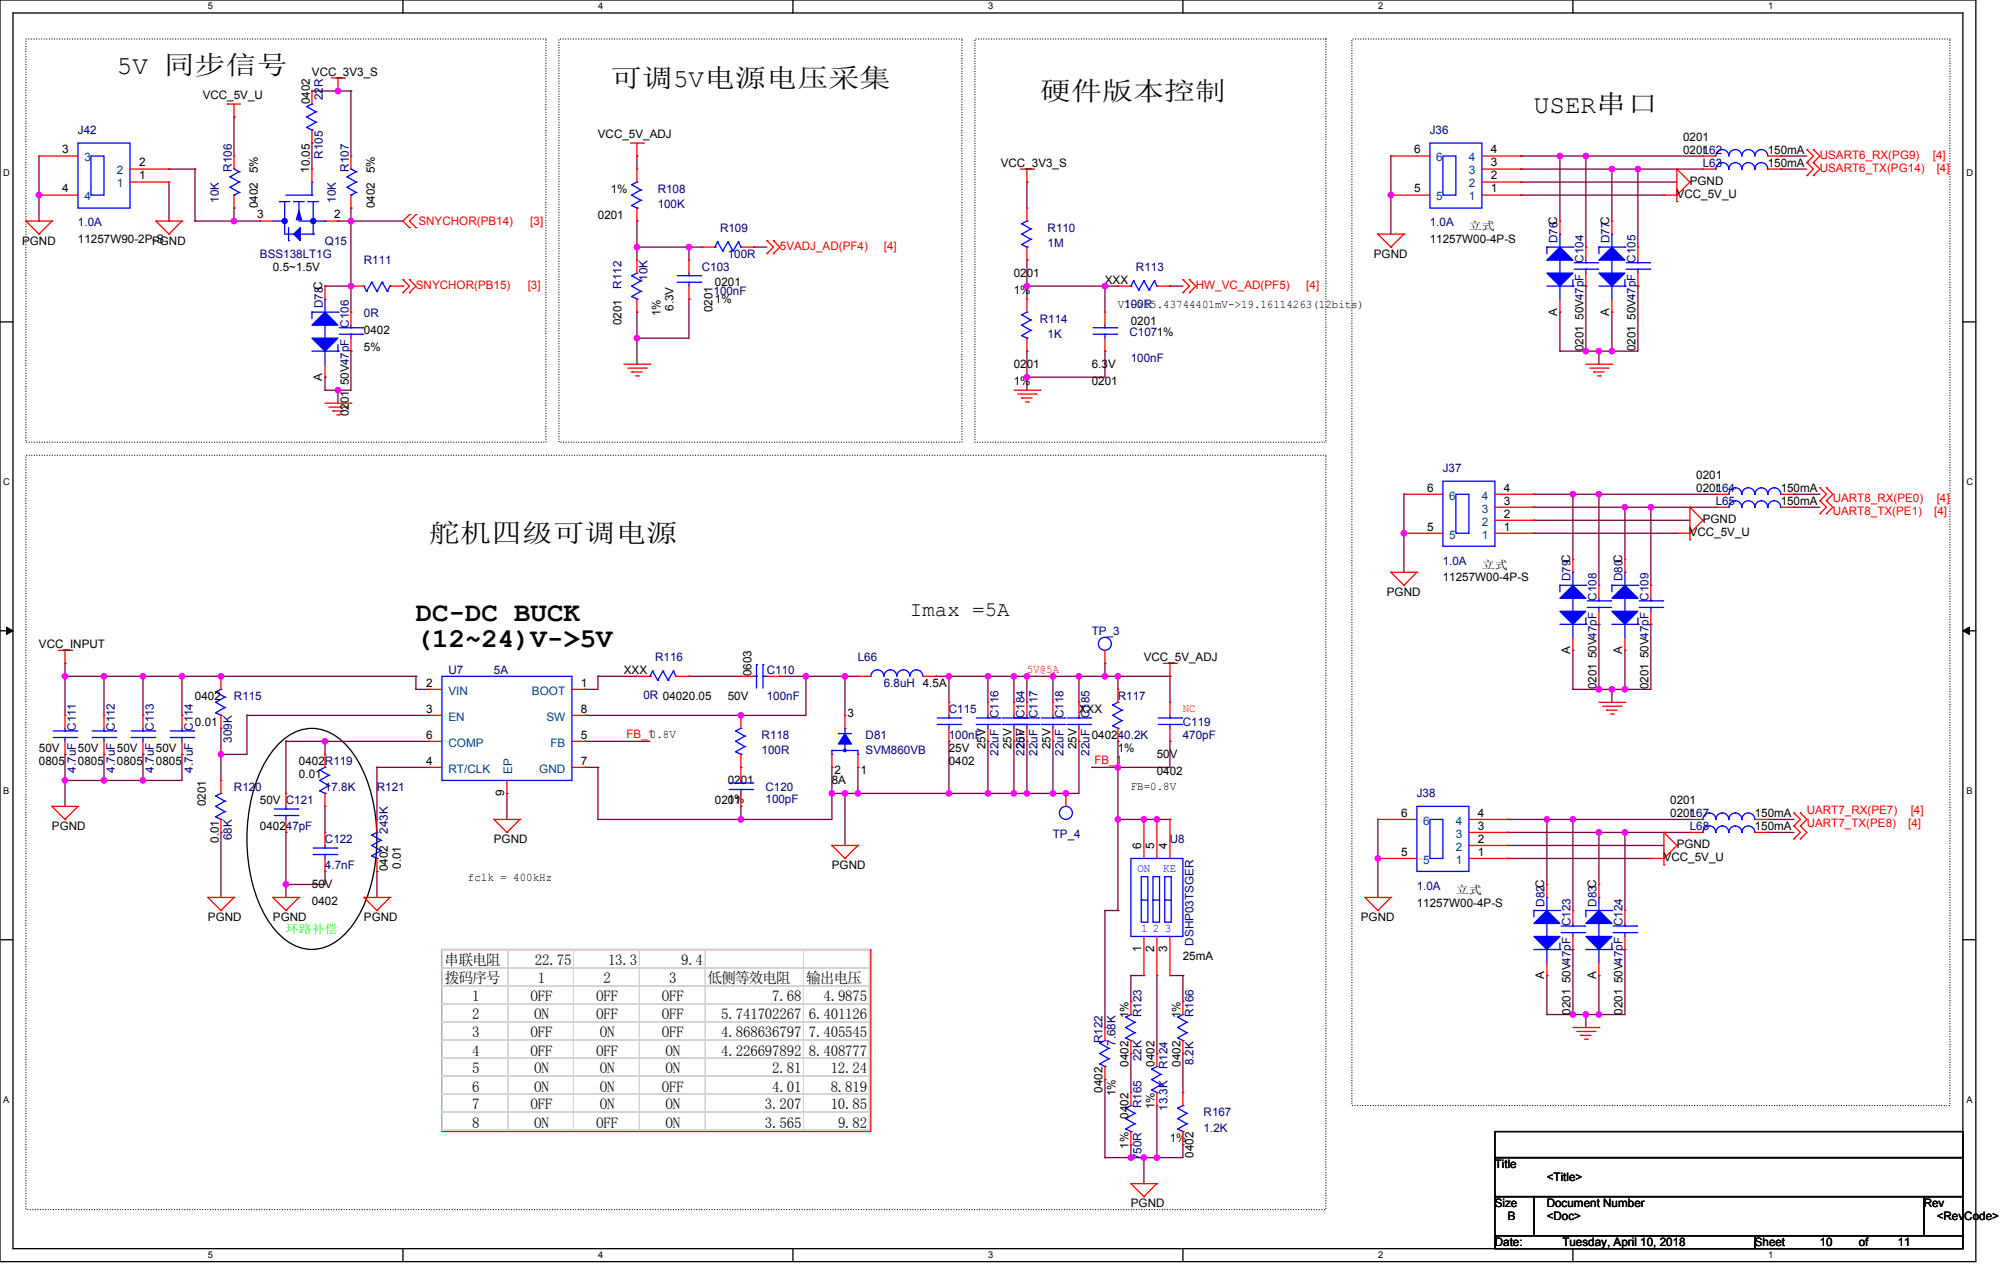
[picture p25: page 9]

串联电阻 | 22.75 | 13.3 | 9.4
拨码序号 | 1 | 2 | 3 | 低侧等效电阻 | 输出电压
1 | OFF | OFF | OFF | 7.68 | 4.9875
2 | ON | OFF | OFF | 5.741702267 | 6.401126
3 | OFF | ON | OFF | 4.868636797 | 7.405545
4 | OFF | OFF | ON | 4.226697892 | 8.408777
5 | ON | ON | ON | 2.81 | 12.24
6 | ON | ON | OFF | 4.01 | 8.819
7 | OFF | ON | ON | 3.207 | 10.85
8 | ON | OFF | ON | 3.565 | 9.82

(15~24)V->12V

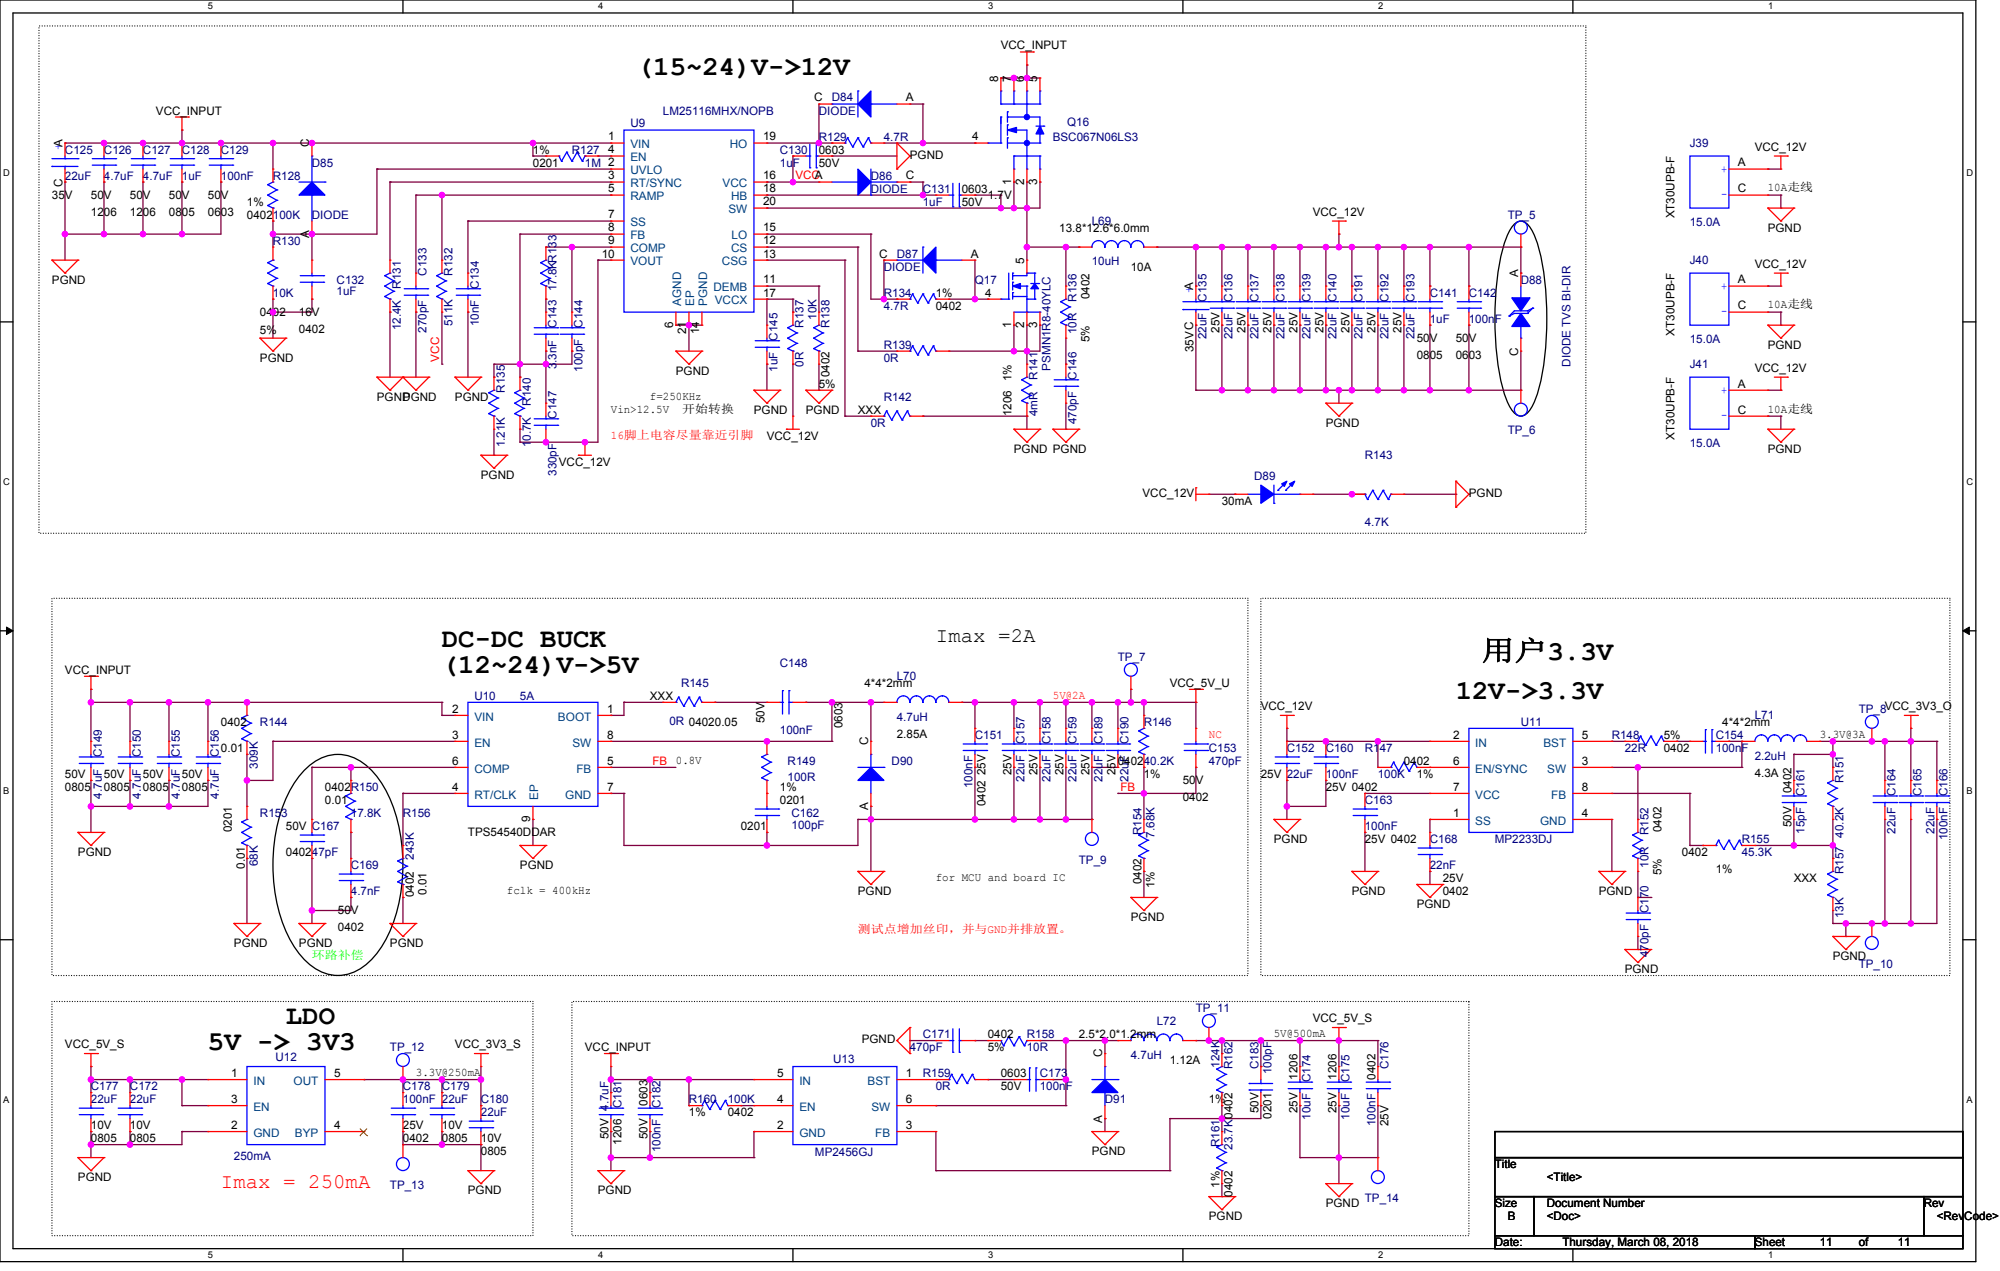
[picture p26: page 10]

DIODE TVS BI-DIR

for MCU and board IC

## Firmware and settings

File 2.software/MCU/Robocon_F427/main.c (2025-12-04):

#include "main.h"

void BSP_Init(void);
void Hardware_Init(void);
void Task_Init(void);

int main(void)
{ 
	BSP_Init();//底层初始化
	Hardware_Init();//硬件初始化TIM_SetCompare1(TIM2,3000);
	Task_Init();//任务初始化
	vTaskStartScheduler(); //开始任务调度
	while(1);
}

//底层初始化函数
void BSP_Init(void)
{
	BSP_GPIO_Init();
	BSP_NVIC_Init();
	BSP_CAN_Init();
	BSP_TIM_Init();
	BSP_USART_Init();
	BSP_DMA_Init();
}

//硬件初始化
void Hardware_Init(void)
{
	Hi219m_ParaInit();
}		

//任务初始化
void Task_Init(void)
{
	P_shH219DataDecode_Binary = xSemaphoreCreateBinary();
	
	//主任务
	xTaskCreate(Task_Main,
				"Task_Main",
				300,
				NULL,
				5,
				NULL);
	
	//键盘控制任务
	xTaskCreate(key_contask,
				"key_contask",
				500,
				NULL,
				4,
				NULL);
	

	//遥控器获取键盘值任务
	xTaskCreate(Task_DataGet,
				"Task_DataGet",
				300,
				NULL,
				4,
				NULL);
	
	//陀螺仪数据解析任务
	xTaskCreate(Task_Hi219mDataDecode,
				"Task_Hi219mDataDecode",
				300,
				NULL,
				4,
				NULL);

	xTaskCreate(Task_TimeCount,
				"Task_TimeCount",
				300,
				NULL,
				4,
				NULL);
}

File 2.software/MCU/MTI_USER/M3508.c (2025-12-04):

#include "M3508.h"

//电机具体配置 初始化电机配置 Can数据解析加入电机位置 对应函数使用
//用户定义电机结构体
//前腿定义在can1,后退定义在can2

//can1
M3508_TypeDef Dog_Leglf1 = {1};//Dog_Leglf1前腿
M3508_TypeDef Dog_Leglf2 = {2};//Dog_Leglf2前腿
M3508_TypeDef Dog_LegRf3 = {3};//Dog_Legrf3前腿
M3508_TypeDef Dog_LegRf4 = {4};//Dog_Legrf4前腿
//can2
M3508_TypeDef Dog_Leglb1 = {1};//Dog_Leglb1前腿
M3508_TypeDef Dog_Leglb2 = {2};//Dog_Leglb2前腿
M3508_TypeDef Dog_LegRb3 = {3};//Dog_Legrb3前腿
M3508_TypeDef Dog_LegRb4 = {4};//Dog_Legrb4前腿


//电机参数初始化
void M3508_ParaInit(Leg_speed_PID speed[],Leg_position_PID position[])
{	
	//Dog_Leg前腿电机配置
	//左前1
	fnPID_SetPara_P_I_D(&Dog_Leglf1.SpeedPID,speed[0].kp_spd ,speed[0].kd_spd );
	fnPID_SetPara_IM(&Dog_Leglf1.SpeedPID,speed[0].minP);
	fnPID_SetPara_OM(&Dog_Leglf1.SpeedPID,speed[0].maxP);
	fnPID_SetPara_P_I_D(&Dog_Leglf1.AnglePID,position[0].kp_pos,position[0].kd_pos);
	fnPID_SetPara_IM(&Dog_Leglf1.AnglePID,position[0].minP);
	fnPID_SetPara_OM(&Dog_Leglf1.AnglePID,position[0].maxP);
	//左前2
	fnPID_SetPara_P_I_D(&Dog_Leglf2.SpeedPID,speed[1].kp_spd ,speed[1].kd_spd);
	fnPID_SetPara_IM(&Dog_Leglf2.SpeedPID,speed[1].minP);
	fnPID_SetPara_OM(&Dog_Leglf2.SpeedPID,speed[1].maxP);
	fnPID_SetPara_P_I_D(&Dog_Leglf2.AnglePID,position[1].kp_pos,position[1].kd_pos);
	fnPID_SetPara_IM(&Dog_Leglf2.AnglePID,position[1].minP );
	fnPID_SetPara_OM(&Dog_Leglf2.AnglePID,position[1].maxP);
	//右前3
	fnPID_SetPara_P_I_D(&Dog_LegRf3.SpeedPID,speed[2].kp_spd ,speed[2].kd_spd);
	fnPID_SetPara_IM(&Dog_LegRf3.SpeedPID,speed[2].minP);
	fnPID_SetPara_OM(&Dog_LegRf3.SpeedPID,speed[2].maxP);
	fnPID_SetPara_P_I_D(&Dog_LegRf3.AnglePID,position[2].kp_pos,position[2].kd_pos);
	fnPID_SetPara_IM(&Dog_LegRf3.AnglePID,position[2].minP);
	fnPID_SetPara_OM(&Dog_LegRf3.AnglePID,position[2].maxP);
	//右前4
	fnPID_SetPara_P_I_D(&Dog_LegRf4.SpeedPID,speed[3].kp_spd ,speed[3].kd_spd);
	fnPID_SetPara_IM(&Dog_LegRf4.SpeedPID,speed[3].minP);
	fnPID_SetPara_OM(&Dog_LegRf4.SpeedPID,speed[3].maxP);
	fnPID_SetPara_P_I_D(&Dog_LegRf4.AnglePID,position[3].kp_pos,position[3].kd_pos);
	fnPID_SetPara_IM(&Dog_LegRf4.AnglePID,position[3].minP);
	fnPID_SetPara_OM(&Dog_LegRf4.AnglePID,position[3].maxP);
	
	//Dog_Leg后腿电机配置
	//左后1
	fnPID_SetPara_P_I_D(&Dog_Leglb1.SpeedPID,speed[4].kp_spd ,speed[4].kd_spd);
	fnPID_SetPara_IM(&Dog_Leglb1.SpeedPID,speed[4].minP);
	fnPID_SetPara_OM(&Dog_Leglb1.SpeedPID,speed[4].maxP);
	fnPID_SetPara_P_I_D(&Dog_Leglb1.AnglePID,position[4].kp_pos,position[4].kd_pos);
	fnPID_SetPara_IM(&Dog_Leglb1.AnglePID,position[4].minP);
	fnPID_SetPara_OM(&Dog_Leglb1.AnglePID,position[4].maxP);
	//左后2
	fnPID_SetPara_P_I_D(&Dog_Leglb2.SpeedPID,speed[5].kp_spd ,speed[5].kd_spd);
	fnPID_SetPara_IM(&Dog_Leglb2.SpeedPID,speed[5].minP);
	fnPID_SetPara_OM(&Dog_Leglb2.SpeedPID,speed[5].maxP);
	fnPID_SetPara_P_I_D(&Dog_Leglb2.AnglePID,position[5].kp_pos,position[5].kd_pos);
	fnPID_SetPara_IM(&Dog_Leglb2.AnglePID,position[5].minP);
	fnPID_SetPara_OM(&Dog_Leglb2.AnglePID,position[5].maxP);
	//右后3
	fnPID_SetPara_P_I_D(&Dog_LegRb3.SpeedPID,speed[6].kp_spd ,speed[6].kd_spd);
	fnPID_SetPara_IM(&Dog_LegRb3.SpeedPID,speed[6].minP);
	fnPID_SetPara_OM(&Dog_LegRb3.SpeedPID,speed[6].maxP);
	fnPID_SetPara_P_I_D(&Dog_LegRb3.AnglePID,position[6].kp_pos,position[6].kd_pos);
	fnPID_SetPara_IM(&Dog_LegRb3.AnglePID,position[6].minP);
	fnPID_SetPara_OM(&Dog_LegRb3.AnglePID,position[6].maxP);
	//右后4
	fnPID_SetPara_P_I_D(&Dog_LegRb4.SpeedPID,speed[7].kp_spd ,speed[7].kd_spd);
	fnPID_SetPara_IM(&Dog_LegRb4.SpeedPID,speed[7].minP);
	fnPID_SetPara_OM(&Dog_LegRb4.SpeedPID,speed[7].maxP);
	fnPID_SetPara_P_I_D(&Dog_LegRb4.AnglePID,position[7].kp_pos,position[7].kd_pos);
	fnPID_SetPara_IM(&Dog_LegRb4.AnglePID,position[7].minP);
	fnPID_SetPara_OM(&Dog_LegRb4.AnglePID,position[7].maxP);

}


//Can数据解析
void fnMotor_CanRecvDataDecode(CAN_TypeDef* canx,CanRxMsg * msg)
{
	if(canx == CAN1)
	{
		//根据对应ID,进行数据解析
		switch(msg->StdId)
		{
			case DOG_LEGLF_1_ID:
			{
				s_fnM3508_RawDataDecode(&Dog_Leglf1,msg);//原始数据解析
			}break;
			
			case DOG_LEGLF_2_ID:
			{
				s_fnM3508_RawDataDecode(&Dog_Leglf2,msg);//原始数据解析
			}break;
			
			case DOG_LEGRF_3_ID:
			{
				s_fnM3508_RawDataDecode(&Dog_LegRf3,msg);//原始数据解析
			}break;
			
			case DOG_LEGRF_4_ID:
			{
				s_fnM3508_RawDataDecode(&Dog_LegRf4,msg);//原始数据解析
			}break;
			default:{}break;
		  }
	}
	else if(canx == CAN2)
	{
		//根据对应ID,进行数据解析
		switch(msg->StdId)
		{
			case DOG_LEGLB_1_ID:
			{
				s_fnM3508_RawDataDecode(&Dog_Leglb1,msg);//原始数据解析
			}break;

			case DOG_LEGLB_2_ID:
			{
				s_fnM3508_RawDataDecode(&Dog_Leglb2,msg);//原始数据解析
			}break;

			case DOG_LEGRB_3_ID:
			{
				s_fnM3508_RawDataDecode(&Dog_LegRb3,msg);//原始数据解析
			}break;

			case DOG_LEGRB_4_ID:
			{
				s_fnM3508_RawDataDecode(&Dog_LegRb4,msg);//原始数据解析
			}break;
		default:{}break;
		}
	}
	
}

//电机控制函数 ************************************************************

//电机速度控制函数 ************
void USE_CAN1_SpeedCotrol_M3508( M3508_TypeDef* st_data,float target_speed)
{
	float ctrl_val;
	
	fnPID_SetTarget(&st_data->SpeedPID,target_speed);//设置目标
	fnPID_SetFeedback(&st_data->SpeedPID,st_data->RecvData.Rotate_FliterSpeed);//获取反馈值;
	fnPID_Calc(&st_data->SpeedPID);//PID计算
	
	ctrl_val = fnPID_GetOutput(&st_data->SpeedPID);//获取控制量
	
	Control_SetCurrentVal(CAN1,st_data->CAN_ID,ctrl_val);//控制执行电机
}


void USE_CAN2_SpeedCotrol_M3508( M3508_TypeDef* st_data,float target_speed)
{
	float ctrl_val;
	
	fnPID_SetTarget(&st_data->SpeedPID,target_speed);//设置目标
	fnPID_SetFeedback(&st_data->SpeedPID,st_data->RecvData.Rotate_FliterSpeed);//获取反馈值;
	fnPID_Calc(&st_data->SpeedPID);//PID计算
	
	ctrl_val = fnPID_GetOutput(&st_data->SpeedPID);//获取控制量
	
	Control_SetCurrentVal(CAN2,st_data->CAN_ID,ctrl_val);//控制执行电机
}

//电机角度控制函数 ************************************************************3508电机角度控制函数 双环PID控制
/////////////////////////角度环前环 ******
void USE_CAN1_ArmMotorCotrol_M3508( M3508_TypeDef* st_data,float target_speed)
{
	float ctrl_val;
	
	fnPID_SetTarget(&st_data->SpeedPID,target_speed);//设置目标
	fnPID_SetFeedback(&st_data->SpeedPID,st_data->RecvData.Rotate_FliterSpeed);//获取反馈值;
	fnPID_Calc(&st_data->SpeedPID);//PID计算
	
	ctrl_val = fnPID_GetOutput(&st_data->SpeedPID);//获取控制量 
	
	Control_SetCurrentVal(CAN1,st_data->CAN_ID,ctrl_val);//控制执行电机
}

void USE_CAN2_ArmMotorCotrol_M3508( M3508_TypeDef* st_data,float target_speed)
{
	float ctrl_val;
	
	fnPID_SetTarget(&st_data->SpeedPID,target_speed);//设置目标
	fnPID_SetFeedback(&st_data->SpeedPID,st_data->RecvData.Rotate_FliterSpeed);//获取反馈值;
	fnPID_Calc(&st_data->SpeedPID);//PID计算
	
	ctrl_val = fnPID_GetOutput(&st_data->SpeedPID);//获取控制量 
	
	Control_SetCurrentVal(CAN2,st_data->CAN_ID,ctrl_val);//控制执行电机
}

/////////////////////////角度后环 ******
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

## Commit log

2025-12-04 Add initial project source files and headers
    Added CMSIS core headers, STM32F4 peripheral drivers, FreeRTOS kernel and portable files, user application source and headers, and project configuration files. This commit establishes the base code s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
2025-12-11 Update Hardware
    [1.7垫片.SLDPRT, 2006法兰盘.SLDPRT, 3508电机.SLDPRT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]
